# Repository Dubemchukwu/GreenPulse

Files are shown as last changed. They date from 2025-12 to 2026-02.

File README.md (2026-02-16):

<div align="center">

# 🌱 GreenPulse

### IoT Plant Monitoring & Smart Irrigation System

*Professional-grade automated plant care through precision sensing and intelligent irrigation*







[Features](#-features) • [Hardware](#-hardware-architecture) • [Getting Started](#-getting-started) • [Documentation](#-documentation) • [Contributing](#-contributing)

---

</div>

## 📖 Overview

GreenPulse is an advanced IoT solution that revolutionizes plant care by combining real-time environmental monitoring with intelligent automated irrigation. Built on the ESP32-C6 Super Mini platform, it monitors soil moisture, temperature, humidity, and atmospheric pressure while synchronizing data to a cloud dashboard and maintaining reliable local control.

**Key Innovation:** Unlike traditional binary irrigation systems that waste up to 40% of water through oversaturation, GreenPulse implements an **Exponential Control Value algorithm** that tapers pump speed as soil moisture approaches the target threshold, preventing water waste and root damage.

### 🎯 Why GreenPulse?

- **Water Conservation**: Reduces water waste by ~40% through precision control
- **Energy Efficient**: Optimized network stack with sub-second connectivity
- **Reliable**: Redundant sensing and FreeRTOS multitasking for zero-latency response
- **User-Friendly**: OLED display with intuitive status indicators
- **Scalable**: Cloud synchronization with local fallback control

---

## ✨ Features

### 🔬 Advanced Sensing
- **Dual Environmental Sensors**: Two BME280 sensors provide redundant temperature, humidity, and pressure monitoring
- **Capacitive Soil Moisture**: Corrosion-resistant probes for long-term reliability
- **Real-time Display**: 0.96" OLED screen with dynamic status indicators

### 💧 Intelligent Irrigation
- **Anti-Overshoot Control**: Exponential tapering prevents water waste
- **PWM Actuator Control**: Variable-speed pumping through ESP32 LEDC peripheral
- **Customizable Thresholds**: Adjust moisture targets for different plant types

### ⚡ Power Optimization
- **Static IP Configuration**: Bypasses DHCP for sub-second network connection
- **WiFi Power-Save Mode**: Reduces idle current consumption
- **Dual 18650 Batteries**: 7-14 days runtime per charge
- **Integrated Charging**: USB Type-C charging module

### 🌐 Connectivity
- **Cloud Synchronization**: Real-time data logging to PythonAnywhere API
- **Local Control**: Operates independently if network unavailable
- **Status Blobs**: Visual WiFi and API sync confirmation on OLED
- **Fast DNS**: Hardcoded 8.8.8.8 for consistent endpoint resolution

### 🖥️ Software Architecture
- **FreeRTOS Multitasking**: Separate UI and control logic for responsive operation
- **Modular Design**: Clean separation between sensors, actuators, networking, and display
- **Resource-First Philosophy**: Optimized for both water and electrical efficiency

---

## 🛠️ Hardware Architecture

### Core Components

| Component | Specification | Purpose | Qty |
|---|---|---|-----|
| **Microcontroller** | ESP32-C6 Super Mini | System brain & WiFi connectivity | 1 |
| **Environmental Sensors** | BME280 (I2C) | Temperature, humidity, pressure (redundant) | 2 |
| **Soil Sensor** | Capacitive Moisture Sensor | Soil hydration monitoring | 2 |
| **Display** | 0.96" SSD1306 OLED (I2C) | Real-time dashboard with status blobs | 1 |
| **Water Pump** | 5V DC Amphibious Motor | Irrigation execution | 1 |
| **Motor Driver** | DRV8833 / L293D | PWM pump speed control | 1 |
| **Tubing** | 6/8mm silicone, 2m | Water delivery | 1 |
| **Batteries** | 18650 Lithium-Ion | Portable power (parallel config) | 2 |
| **Charging Module** | Type-C Lithium Charger | Battery management | 1 |
| **Power Switch** | Latching Toggle Switch | System power control | 1 |
| **Prototyping Board** | Veroboard 9x15cm | Component mounting | 1 |
| **Connectors** | Female Headers (10x10 pins) | Modular connections | As needed |
| **Wiring** | 22AWG wire, 5m | Electrical connections | 1 |
| **Enclosure** | Custom housing | Weather protection | 1 |

### Pin Configuration (ESP32-C6)

```
I2C Bus 0 (Sensors):
├─ SDA: GPIO 6
└─ SCL: GPIO 7
   ├─ BME280 Sensor 1
   └─ SSD1306 OLED Display

I2C Bus 1 (Redundant Sensor):
├─ SDA: GPIO 9
└─ SCL: GPIO 8
   └─ BME280 Sensor 2

Analog Inputs:
├─ GPIO 0: Soil Moisture Sensor 1 (ADC)
└─ GPIO 1: Soil Moisture Sensor 2 (ADC)

Pump Control (DRV8833):
├─ GPIO 19: Motor Input 1 (AIN1)
├─ GPIO 20: Motor Input 2 (AIN2)
└─ GPIO 18: PWM Control / Standby

Status LED:
└─ GPIO 8: Internal RGB LED

Power:
├─ 5V: From battery management system
└─ GND: Common ground
```

### Hardware Images

<!-- Add your hardware images here -->
<div align="center">

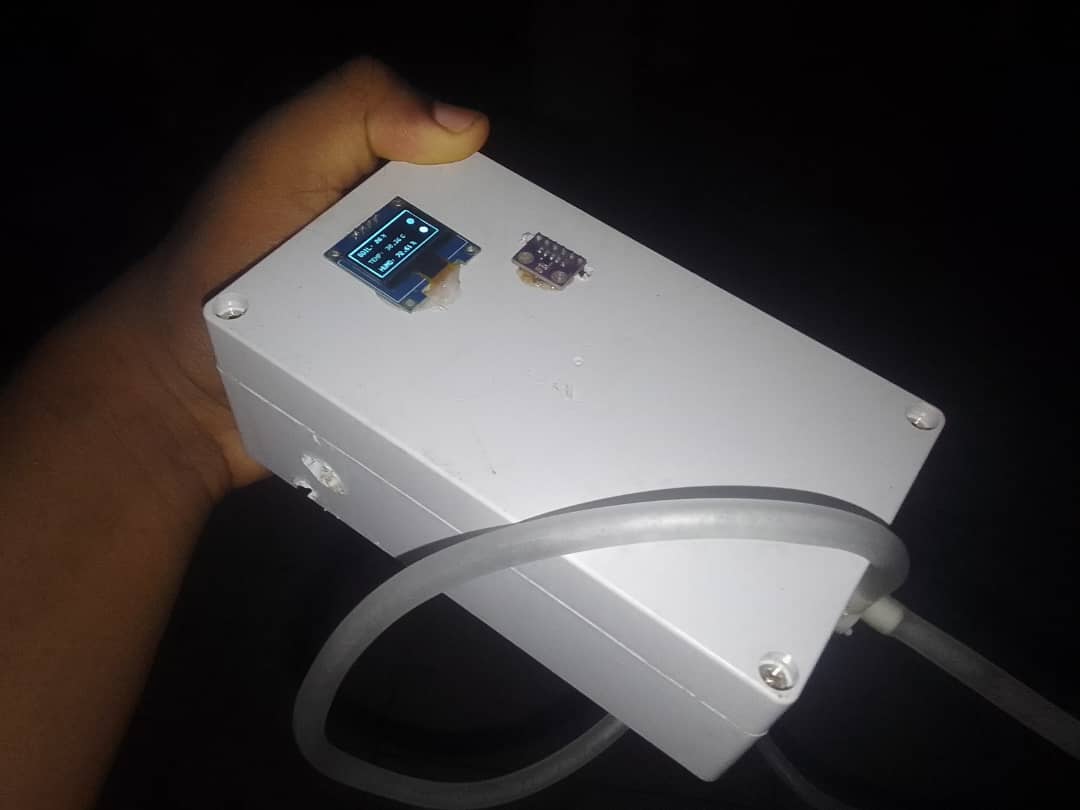
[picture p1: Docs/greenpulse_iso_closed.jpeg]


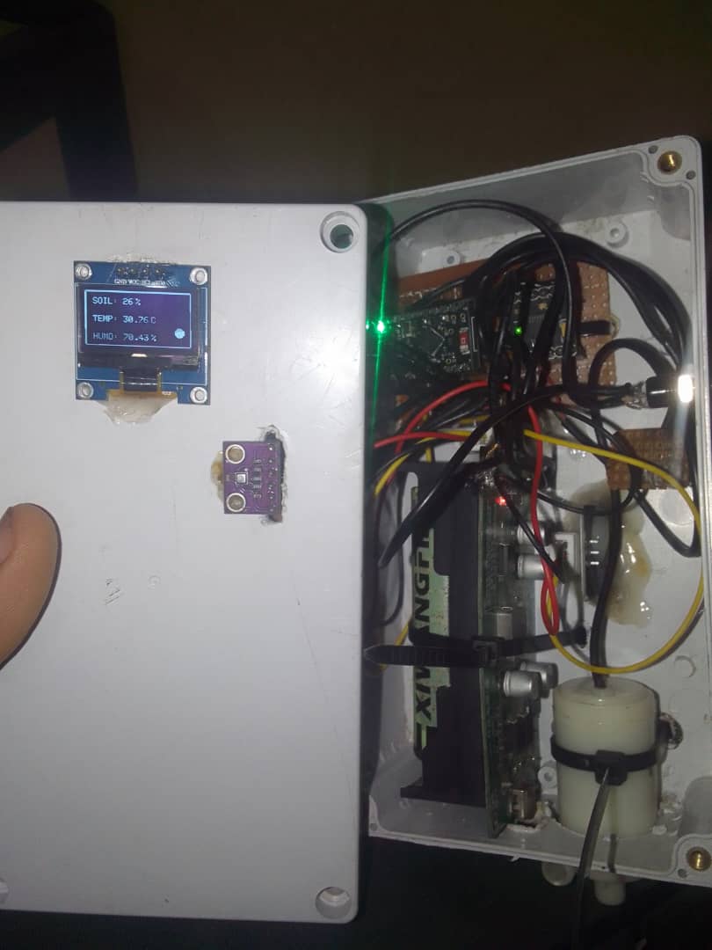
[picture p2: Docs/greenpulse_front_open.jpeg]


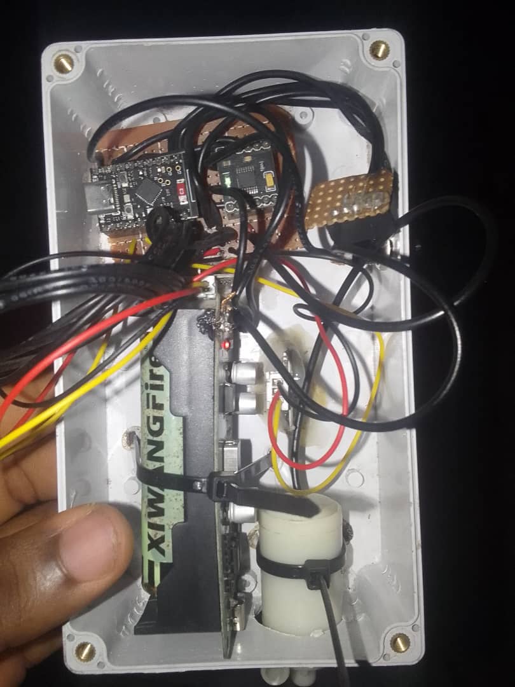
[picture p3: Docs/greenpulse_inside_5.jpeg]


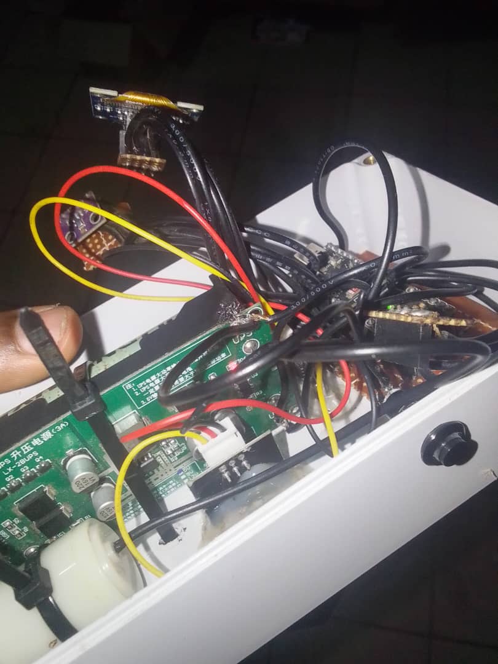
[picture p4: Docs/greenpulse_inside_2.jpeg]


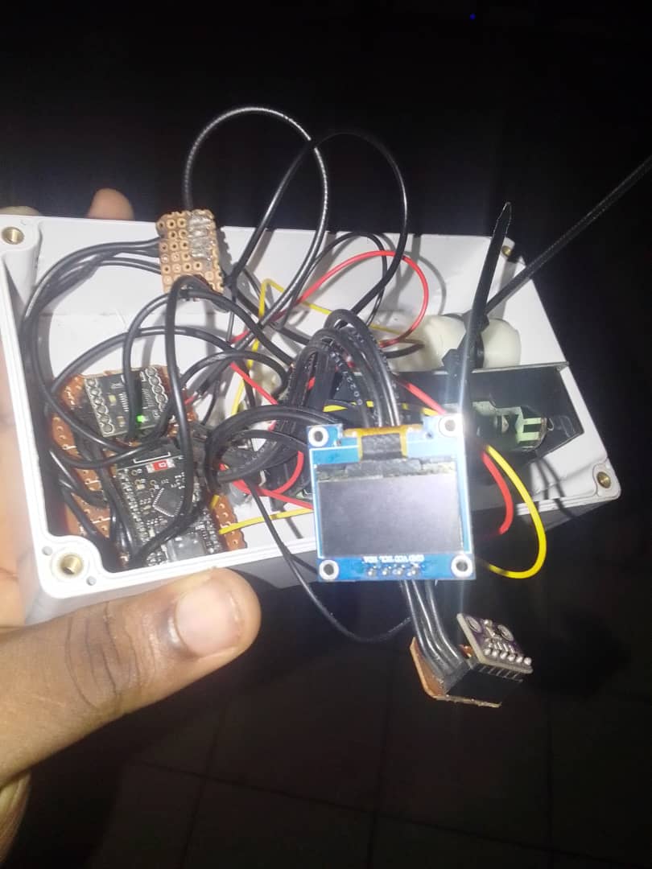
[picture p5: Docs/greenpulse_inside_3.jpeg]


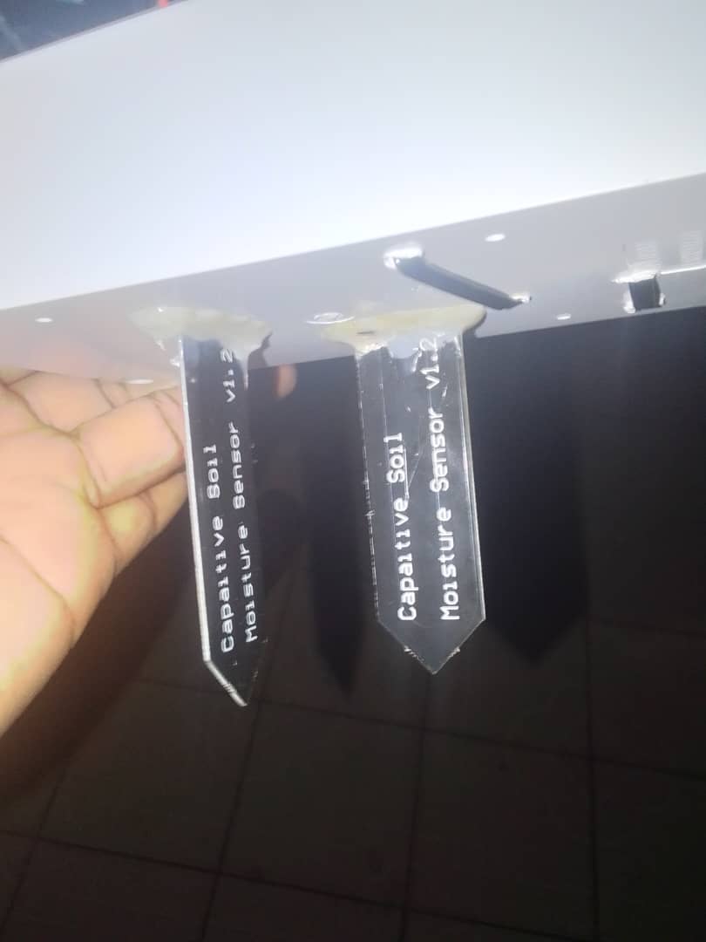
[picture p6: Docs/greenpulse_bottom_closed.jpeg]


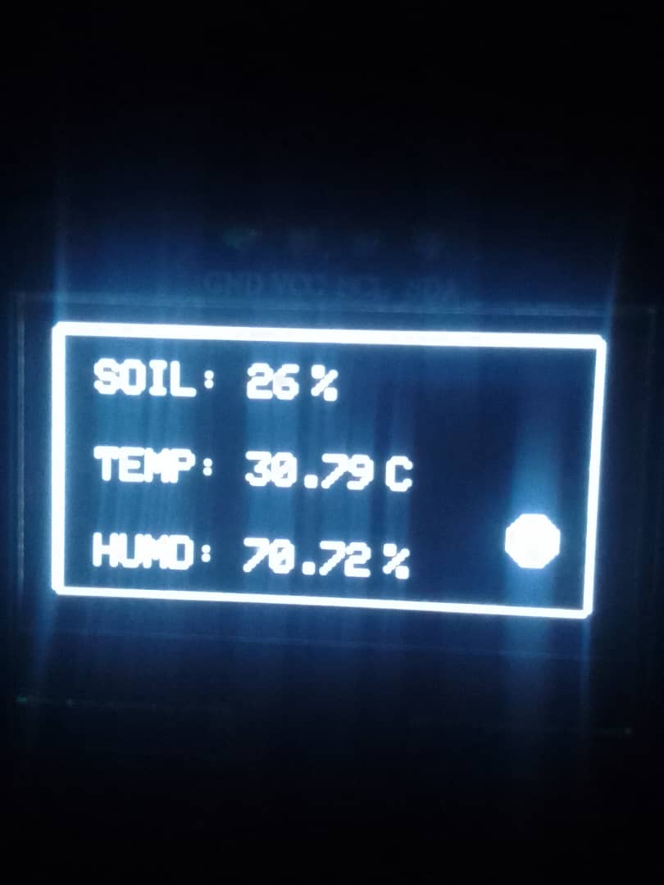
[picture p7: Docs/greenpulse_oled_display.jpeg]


</div>

---

## 🚀 Getting Started

### Prerequisites

**Hardware Requirements:**
- All components listed in [Hardware Architecture](#core-components)
- Soldering iron and supplies
- Multimeter for testing
- USB-C cable for programming

**Software Requirements:**
- [Arduino IDE](https://www.arduino.cc/en/software) 2.0 or later
- ESP32 board support package (v3.0.0+)
- Git for cloning the repository

### Installation

#### 1. Clone the Repository

```bash
git clone https://github.com/yourusername/greenpulse.git
cd greenpulse
```

#### 2. Install Arduino Libraries

Open Arduino IDE and install the following libraries via Library Manager (`Sketch > Include Library > Manage Libraries`):

- **Adafruit SSD1306** (for OLED display)
- **Adafruit BME280** (for environmental sensors)
- **Arduino_JSON** (for API communication)
- **WiFi** (included with ESP32 core)

Alternatively, install via command line:

```bash
arduino-cli lib install "Adafruit SSD1306"
arduino-cli lib install "Adafruit BME280 Library"
arduino-cli lib install "Arduino_JSON"
```

#### 3. Configure ESP32 Board

1. Open Arduino IDE
2. Go to `File > Preferences`
3. Add this URL to "Additional Board Manager URLs":
   ```
   https://espressif.github.io/arduino-esp32/package_esp32_index.json
   ```
4. Go to `Tools > Board > Board Manager`
5. Search for "esp32" and install version 3.0.0 or later
6. Select `Tools > Board > ESP32C6 Dev Module`

#### 4. Configure Network Settings

Open `Firmware/Config.h` and `Firmware/Wifi.cpp` to update your network credentials:

**In `Firmware/Config.h`:**
```cpp
#define SSID1 "YourNetworkName"
#define PASSWORD1 "YourPassword"
#define SSID2 "BackupNetwork"      // Optional second network
#define PASSWORD2 "BackupPassword"
#define API_ENDPOINT "dubemguy.pythonanywhere.com"  // Your API endpoint
#define PORT 80
```

**In `Firmware/Wifi.cpp`:**
```cpp
// Static IP Configuration (adjust for your network)
IPAddress localIP(192, 168, 70, 137);    // Choose available IP in your subnet
IPAddress gateway(192, 168, 70, 166);    // Your router's IP address
IPAddress subnet(255, 255, 255, 0);      // Standard subnet mask
IPAddress dns(8, 8, 8, 8);               // Google DNS for reliability
```

**Network Features:**
- Primary and backup SSID support for redundancy
- Static IP bypasses DHCP for faster connection
- WiFi power set to 8.5dBm (balanced range and efficiency)
- Auto-reconnect with retry logic (7 attempts, 2-second intervals)

#### 5. Configure API Endpoint (Optional)

The API endpoint is already configured in `Firmware/Config.h`:

```cpp
#define API_ENDPOINT "dubemguy.pythonanywhere.com"
#define PORT 80
```

To use your own backend:
- Replace with your PythonAnywhere URL or custom server
- Keep PORT as 80 for HTTP (or 443 for HTTPS with appropriate SSL configuration)
- The system automatically handles connection, data upload (PUT), and remote control (GET)

If you don't want cloud sync, the system works fully offline using only the OLED display for monitoring.

#### 6. Upload to ESP32-C6

1. Connect ESP32-C6 to your computer via USB-C
2. Select the correct port: `Tools > Port > [Your ESP32 Port]`
3. Click the Upload button (→) in Arduino IDE
4. Wait for compilation and upload to complete

---

## 🔧 Hardware Assembly

### Step-by-Step Build Guide

#### Phase 1: Prepare the Veroboard

1. **Plan Your Layout**
   - Sketch component positions on paper first
   - Place ESP32-C6 centrally for optimal wire routing
   - Position power components (batteries, charging module) at one end
   - Keep sensors near the edge for easy external mounting

2. **Cut Veroboard to Size**
   - Recommended: 9cm x 15cm
   - Use a hacksaw or scoring tool
   - Smooth edges with sandpaper

#### Phase 2: Mount Core Components

3. **Install the ESP32-C6**
   - Solder female headers to the veroboard (2 rows of 10 pins)
   - Test fit the ESP32-C6 module
   - Ensure USB-C port is accessible from enclosure edge

4. **Mount Power System**
   - Solder the Type-C charging module
   - Install the latching power switch
   - Prepare battery holder or mounting for 18650 cells
   - Connect batteries in **parallel** (positive to positive, negative to negative)
   
   ⚠️ **IMPORTANT**: Parallel connection extends runtime. Series connection (NOT recommended) would provide 7.4V and damage 5V components!

5. **Install Motor Driver**
   - Solder DRV8833 to veroboard
   - Leave space between driver and ESP32 for heat dissipation
   - Ensure output pins are accessible for pump wiring

#### Phase 3: Connect Sensors

6. **Wire BME280 Sensors (I2C)**
   
   **Sensor 1 (Primary):**
   ```
   BME280 Pin → ESP32-C6 Pin
   VCC        → 3.3V
   GND        → GND
   SDA        → GPIO 6
   SCL        → GPIO 7
   ```
   
   **Sensor 2 (Redundant):**
   ```
   BME280 Pin → ESP32-C6 Pin
   VCC        → 3.3V
   GND        → GND
   SDA        → GPIO 9
   SCL        → GPIO 8
   ```

7. **Wire OLED Display (I2C)**
   ```
   OLED Pin   → ESP32-C6 Pin
   VCC        → 3.3V
   GND        → GND
   SDA        → GPIO 6 (shared with BME280 Sensor 1)
   SCL        → GPIO 7 (shared with BME280 Sensor 1)
   ```

8. **Connect Soil Moisture Sensors**
   ```
   Sensor 1:
   VCC        → 3.3V
   GND        → GND
   AOUT       → GPIO 0
   
   Sensor 2:
   VCC        → 3.3V
   GND        → GND
   AOUT       → GPIO 1
   ```

#### Phase 4: Wire the Pump System

9. **Connect DRV8833 Motor Driver**
   ```
   DRV8833    → ESP32-C6
   VCC        → 5V (from battery system)
   GND        → GND
   AIN1       → GPIO 19
   AIN2       → GPIO 20
   STBY       → GPIO 18 (PWM control)
   
   Motor Outputs:
   AOUT1      → Water Pump (+)
   AOUT2      → Water Pump (-)
   ```

10. **Attach Tubing**
    - Connect 6/8mm silicone tubing to pump inlet
    - Route outlet tubing to plant location
    - Secure all connections with zip ties or clamps

#### Phase 5: Power Wiring

11. **Wire Power Distribution**
    ```
    Battery (+) → Power Switch → Charging Module (+) → Distribution Bus
    Battery (-) → Charging Module (-) → GND Bus
    
    From Distribution Bus:
    → ESP32-C6 VIN (5V)
    → DRV8833 VCC (5V)
    → Voltage divider → ESP32 ADC (for battery monitoring)
    
    All grounds connect to common GND bus
    ```

12. **Add Decoupling Capacitors** (Recommended)
    - 100µF electrolytic capacitor across 5V and GND near ESP32
    - 10µF ceramic capacitor across 3.3V and GND
    - Reduces noise and improves stability

#### Phase 6: Testing & Enclosure

13. **Pre-Enclosure Testing**
    - Connect USB-C and verify ESP32 powers on
    - Check OLED display shows boot screen
    - Verify WiFi connection in Serial Monitor
    - Test sensor readings appear on display
    - Manually trigger pump to confirm operation

14. **Final Assembly**
    - Mount completed board in enclosure
    - Drill holes for:
      - OLED display window
      - Power switch access
      - USB-C charging port
      - Sensor wire pass-throughs
      - Tubing exit
    - Use hot glue or mounting standoffs to secure board
    - Seal wire entry points with silicone (optional, for outdoor use)

15. **External Connections**
    - Route sensor wires through enclosure
    - Position BME280 sensors for ambient air monitoring
    - Insert soil moisture sensors into plant soil
    - Coil excess tubing neatly

### Wiring Diagram

<!-- Add wiring diagram image here -->
##### BreadBoard View
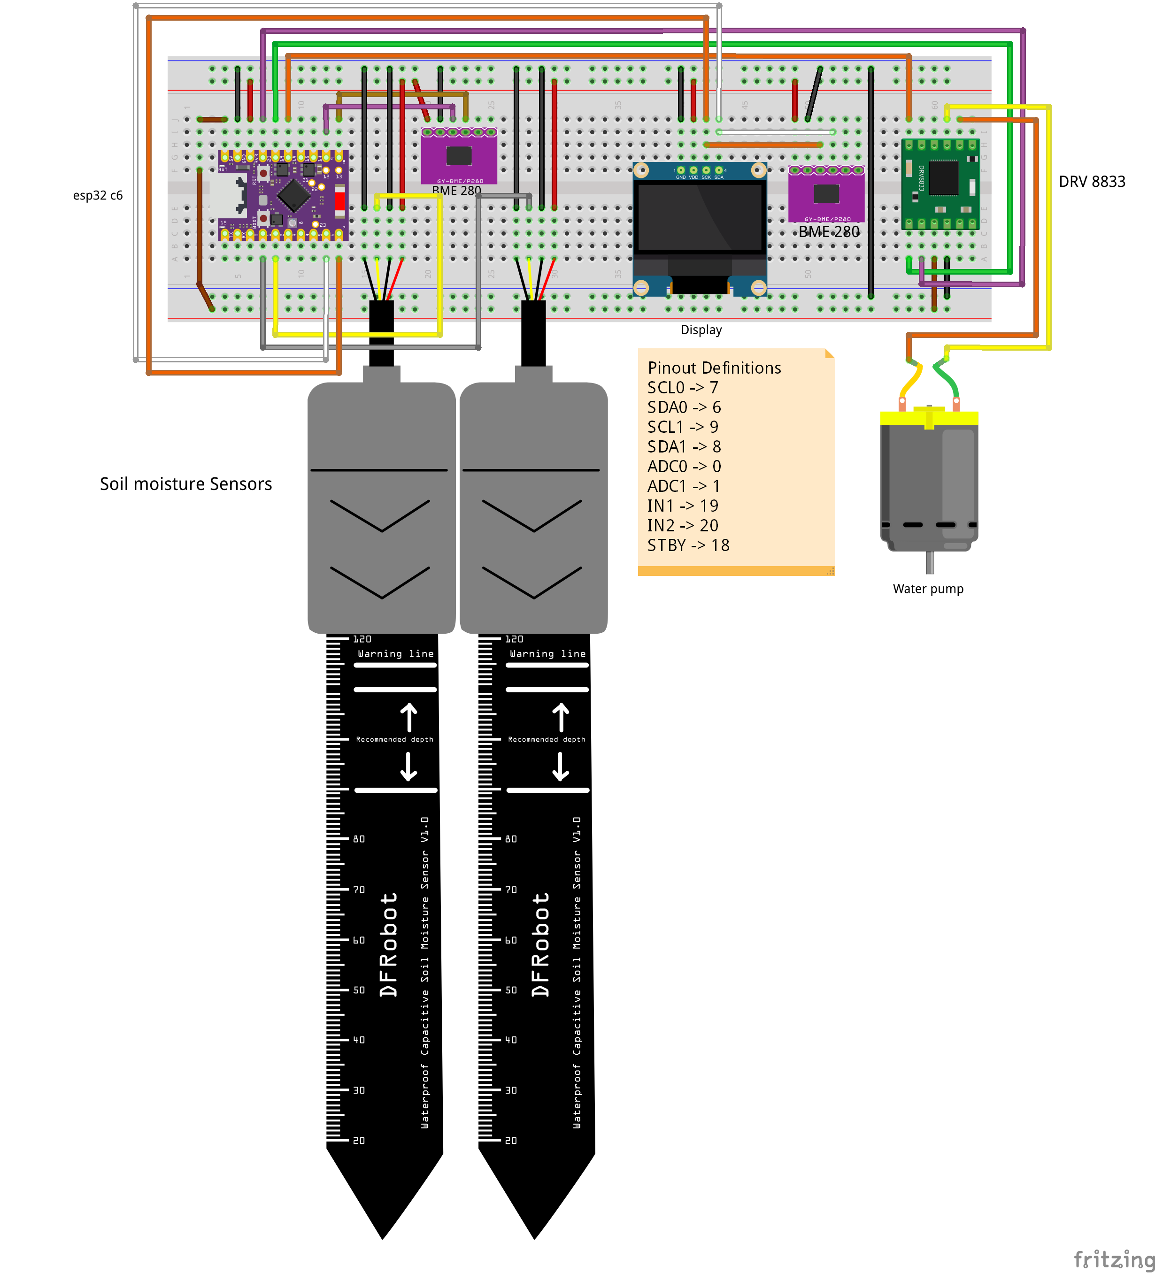
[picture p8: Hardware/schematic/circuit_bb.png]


##### Schematic Diagram
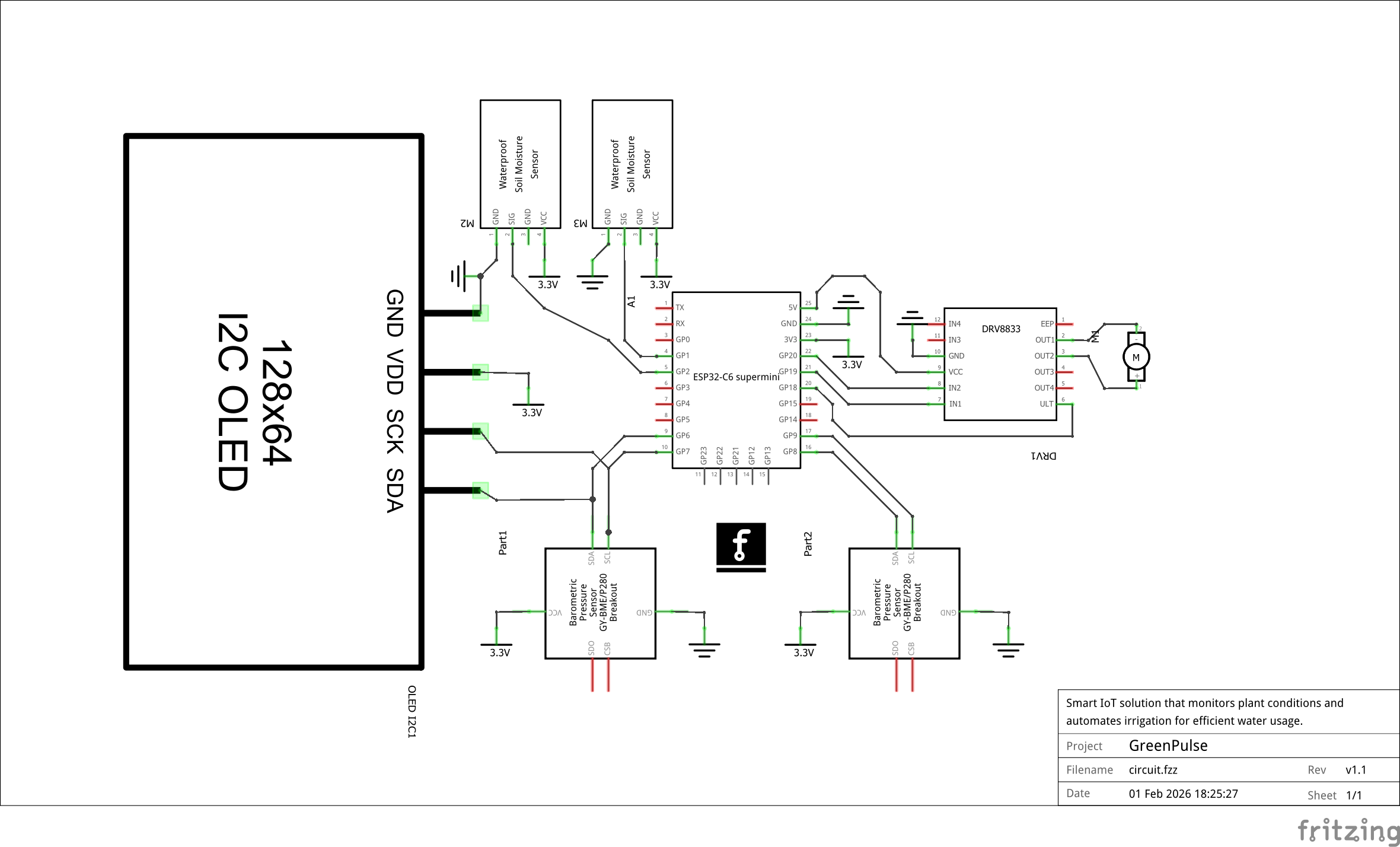
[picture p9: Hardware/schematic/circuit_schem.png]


---

## 📊 Software Architecture

### Module Overview

```
greenpulse/
├── Firmware/
│   ├── Firmware.ino          # Main entry point, FreeRTOS task management
│   ├── Config.h              # Global configuration and constants
│   ├── Wifi.cpp              # Network stack (Static IP, WiFi Sleep, DNS)
│   ├── Networks.h            # Network configuration
│   ├── Sensors.h             # BME280 & moisture sensor fusion logic
│   ├── Actuator.cpp/.h       # Pump control with PWM and exponential tapering
│   ├── OledUI.cpp            # Display rendering and status blob indicators
│   ├── Display.h             # Display configuration
│   ├── Api.cpp               # Cloud synchronization (PythonAnywhere)
│   ├── Logger.cpp            # Logging utilities
│   ├── Utils.h               # Utility functions
│   ├── SoilMoistureSensor.cpp    # Soil moisture sensor interface
│   └── TempXHumiditySensor.cpp   # BME280 sensor interface
├── ApiService/               # Backend API code
├── Hardware/                 # Circuit diagrams and PCB layouts
├── Docs/                     # Documentation
└── README.md
```

### Key Algorithms

#### 1. Variable-Speed Pump Control

The pump control system uses PWM (Pulse Width Modulation) for precise water delivery:

**Algorithm:**
- Speed is specified as a percentage (0-100%)
- System converts percentage to PWM duty cycle (0-255)
- Direction control: Forward pumps water into soil, reverse drains to reservoir
- Standby pin enables/disables pump operation
- Speed can be adjusted in real-time to prevent over-watering

**Benefits:**
- Gentle watering prevents soil erosion
- Variable flow rates allow precise moisture control
- Reversible pump can drain excess water if needed
- PWM frequency (10kHz) ensures quiet, smooth operation

#### 2. Optimized WiFi Connection Stack

Power-efficient networking through multiple optimization techniques:

**Static IP Configuration:**
- Pre-configured IP address (192.168.70.137)
- Gateway and subnet mask hardcoded
- DNS server set to Google DNS (8.8.8.8)
- Bypasses DHCP handshake, saving 2-3 seconds per connection

**WiFi Power Management:**
- Power level set to 8.5dBm (balanced range and efficiency)
- WiFi sleep mode enabled between data transmissions
- Auto-reconnect disabled (manual control for better error handling)
- Hostname set to "GreenPulse" for easy network identification

**Connection Retry Logic:**
- Maximum 7 retry attempts with 2-second intervals
- Automatic reconnection if WiFi drops
- System restart after repeated failures
- Status indicators update display during connection process

**Result:** Achieves sub-second network readiness after initial connection, significantly reducing power consumption during idle periods.

#### 3. FreeRTOS Dual-Task Architecture

Separates display rendering from sensor/control operations for responsive performance:

**Display Manager Task:**
- Updates OLED screen with current readings
- Refreshes sensor values every 1 second
- Updates WiFi and API status blobs in real-time
- Handles screen transitions (Home ↔ WiFi status)
- Runs independently to prevent UI freezing

**Logic Manager Task:**
- Reads soil moisture from dual capacitive sensors (averaged)
- Polls BME280 sensors for temperature, humidity, pressure
- Makes watering decisions based on moisture thresholds
- Executes pump control with variable speed
- Manages API synchronization cycles

**Screen Management:**
- **HOME screen:** Displays soil moisture %, temperature, humidity, and status blobs
- **WIFI screen:** Shows connection status ("Wi-Fi connected" or "you are offline")
- Automatic timeout returns to HOME after 4 seconds

**Efficient Rendering:**
- Only updates changed values (partial screen refresh)
- Status blobs toggle between filled (white) and empty (black) circles
- Reduces flicker and improves battery life

#### 4. Dual-Sensor Averaging Algorithm

Increases reliability through sensor redundancy:

**Soil Moisture Processing:**
- Two capacitive sensors (GPIO 0 and GPIO 1) provide independent readings
- System averages both sensors for final moisture value
- Individual sensor readings available for troubleshooting
- Raw ADC values (0-4095) converted to percentage (0-100%)

**Temperature & Humidity Fusion:**
- Two BME280 sensors on separate I2C buses (Wire and Wire1)
- Primary sensor (Wire, GPIO 6/7) handles main readings
- Secondary sensor (Wire1, GPIO 8/9) provides backup
- Initialization retry logic (up to 5 attempts per sensor)
- Graceful degradation if one sensor fails

**Calculation Method:**
- Soil moisture: `(Sensor1 + Sensor2) / 2` then scale to percentage
- Temperature/Humidity: Individual sensor or averaged based on availability
- Pressure reading available but primarily for environmental logging

**Error Handling:**
- Returns NULL if sensor initialization fails
- Serial debug messages indicate which I2C bus has issues
- System continues operating with remaining functional sensors

#### 5. Cloud API Synchronization Protocol

Efficient data transmission to PythonAnywhere backend:

**Data Upload (PUT Request):**
- Collects current sensor readings (temperature, humidity, pressure, soil moisture)
- Packages data into JSON format
- Sends HTTP PUT request to API endpoint (dubemguy.pythonanywhere.com:80)
- Includes proper headers: Content-Type, Content-Length, User-Agent
- 5-second timeout prevents indefinite blocking
- Returns success/failure status for display blob update

**Remote Control (GET Request):**
- Fetches pump control commands from API
- Parses JSON response for pump state
- 3-second timeout for faster failure detection
- Validates HTTP 200 status code before processing
- Extracts JSON from response body (handles extra whitespace)

**Connection Management:**
- Creates new NetworkClient for each request
- Properly closes connections after data transfer
- Cleans up memory by deleting client objects
- Only attempts sync when WiFi is connected
- Fails gracefully if network unavailable

**Status Indication:**
- Updates `updateApiState` flag based on success/failure
- Display shows white blob when last sync succeeded
- Black blob indicates sync failure or timeout
- Allows local operation even if API is unavailable

---

## 📱 User Interface

### OLED Display Layout

```

┌─────────────────────────┐
│ SOIL: 45%               │
│                      ●  │
│ TEMP: 24.50 C           │
│                      ●  │    
│ HUMD: 62.00 %           │
└─────────────────────────┘

[Status Blobs] ← API (top), WiFi (bottom)

```

### Status Blob Indicators

**Top Blob (API Sync):**
- ⚪ **White (Filled)**: Last cloud sync successful (`updateApiState = true`)
- ⚫ **Black (Empty)**: Sync failed, timeout, or not attempted
- Position: Right side, aligned with temperature line

**Bottom Blob (WiFi):**
- ⚪ **White (Filled)**: WiFi connected (`wifiIsConnected = true`)
- ⚫ **Black (Empty)**: WiFi disconnected
- Position: Right side, aligned with humidity line

These provide instant visual confirmation without reading text, perfect for quick system checks from a distance.

### WiFi Status Screen

When WiFi state changes, the display automatically switches to show connection status:

**Connected:**
```
┌─────────────────────────┐
│                         │
│     Wi-Fi connected     │
│                         │
│         Online          │
│                         │
└─────────────────────────┘
```

**Disconnected:**
```
┌─────────────────────────┐
│                         │
│       Looks like        │
│                         │
│     you are offline     │
│                         │
└─────────────────────────┘
```

Display automatically returns to HOME screen after 4 seconds.

---

## 🔬 Calibration Guide

### Initial Setup (Required)

#### Soil Moisture Calibration

Each sensor requires calibration for your specific soil type:

1. **Dry Reading**
   - Remove sensor from soil completely
   - Let air dry for 5 minutes
   - Note the reading from Serial Monitor: `Dry Value: XXXX`

2. **Wet Reading**
   - Submerge sensor tip in water (not fully, just the sensing area)
   - Wait 30 seconds for reading to stabilize
   - Note the reading: `Wet Value: XXXX`

3. **Update Code**
   
   In `Firmware/SoilMoistureSensor.cpp`, the `SoilMoistureTranslator()` function converts raw ADC values (0-4095) to percentage (0-100%). The current implementation uses a simple linear scaling:
   
   ```
   Percentage = (RawValue × 100) / 4095
   ```
   
   For more accurate readings with your specific soil type, you may want to modify this function to use your calibration values with proper mapping.

4. **Verify**
   - Insert sensor in dry soil: should read ~0-20%
   - Water thoroughly: should read ~80-100%
   - Adjust map values if readings seem incorrect

#### Pump Flow Rate Testing

1. **Measure Flow**
   - Place pump outlet in measuring cup
   - Run at 100% PWM for 60 seconds
   - Measure water volume (ml)

2. **Calculate Duration**
   ```
   Example: 500ml in 60 seconds = 8.3ml/second
   
   For 100ml watering:
   Duration = 100ml ÷ 8.3ml/s = 12 seconds
   ```

3. **Update Code**
   
   In `Firmware/Config.h`, update the pump flow rate constants based on your measurements. This ensures accurate watering duration calculations.

---

## 🌐 API Integration (Optional)

GreenPulse can synchronize data to a cloud API for remote monitoring and historical analysis.

### Setting Up PythonAnywhere Backend

1. **Create Account**
   - Sign up at [pythonanywhere.com](https://www.pythonanywhere.com)
   - Free tier supports up to 100k API requests/day

2. **Deploy FastAPI Application**

   Create `main.py`:
   ```python
   from fastapi import FastAPI
   from pydantic import BaseModel
   from datetime import datetime
   
   app = FastAPI()
   
   class SensorData(BaseModel):
       device_id: str
       timestamp: str
       moisture: float
       temperature: float
       humidity: float
       pressure: float
       pump_status: bool
   
   @app.post("/api/data")
   async def receive_data(data: SensorData):
       # Store in database or log file
       print(f"Received from {data.device_id}: {data.moisture}% moisture")
       return {"status": "success", "received_at": datetime.now().isoformat()}
   
   @app.get("/api/status/{device_id}")
   async def get_status(device_id: str):
       # Return latest data for device
       return {"device_id": device_id, "online": True}
   ```

3. **Configure ESP32**
   
   Update `Firmware/Config.h`:
   ```cpp
   #define API_ENDPOINT "https://yourusername.pythonanywhere.com/api/data"
   #define DEVICE_ID "greenpulse-001"
   #define SYNC_INTERVAL 60000  // milliseconds (60 seconds)
   ```

### Data Payload Structure

The ESP32 sends JSON data every minute:

```json
{
    "soil_moisture": 45.2,
    "temperature": 24.5,
    "humidity": 62.3,
    "pressure": 1013.2,
    "pump": "on"
}
```

### Local-Only Operation

If you prefer not to use cloud sync:
- Comment out `updateAPI()` calls in `Firmware/Firmware.ino`
- System operates fully offline
- All data visible on OLED display
- Serial Monitor shows detailed logs

---

## 🔋 Power Management

### Battery Life Optimization

**Expected Runtime:**
- Normal operation: 7-14 days per charge
- With WiFi sleep enabled: Up to 3 weeks
- Deep sleep mode (optional): 1-2 months

**Current Consumption:**

| Mode | Current Draw | Notes |
|---|---|---|
| Active (WiFi on) | ~120mA | During API sync |
| Active (WiFi sleep) | ~50mA | Normal sensing |
| Pump running (max) | ~200mA | Brief periods |
| Deep sleep | ~10µA | Not implemented by default |

### Charging

- **Input**: USB Type-C, 5V/1-2A
- **Charging Time**: 4-6 hours for dual 2500mAh cells
- **LED Indicator**: Red (charging), Green/Blue (complete)
- **Protection**: Built-in over-charge/discharge protection

### Extending Battery Life

1. **Reduce Sync Frequency**
   ```cpp
   #define SYNC_INTERVAL 300000  // 5 minutes instead of 1
   ```

2. **Enable Deep Sleep** (Advanced)
   
   For maximum battery life, implement deep sleep mode where the ESP32 wakes periodically to check sensors. Note: This disables WiFi and OLED between wake cycles.

3. **Lower Display Brightness**
   
   Enable the dim mode for the OLED display in `Firmware/OledUI.cpp` setup function.

---

## 🛠️ Troubleshooting

### Common Issues & Solutions

#### Display Not Working

**Symptom**: OLED remains blank after power-on

**Solutions:**
1. **Check I2C address**
   
   Most SSD1306 displays use address 0x3C, but some use 0x3D. Check your display documentation or try the alternate address in `Firmware/OledUI.cpp`.

2. **Run I2C scanner**
   
   Upload the I2C scanner sketch (available in Arduino Examples > Wire > i2c_scanner) to detect the actual address of your display.

3. **Verify wiring**
   - SDA must connect to GPIO 6
   - SCL must connect to GPIO 7
   - VCC should be 3.3V (not 5V)
   - Check for cold solder joints

4. **Check power**
   - OLED requires stable 3.3V
   - Add 10µF capacitor across VCC/GND if flickering

---

#### Pump Not Activating

**Symptom**: Moisture drops but pump doesn't turn on

**Solutions:**
1. **Verify DRV8833 connections**
   ```
   Check:
   - VCC connected to 5V (not 3.3V)
   - GND connected
   - AIN1 → GPIO 19
   - AIN2 → GPIO 20
   - STBY → GPIO 18
   ```

2. **Test pump separately**
   
   Add test code to the `setup()` function to manually run the pump for 2 seconds and verify it's working independently of the moisture control logic.

3. **Check motor driver**
   - Measure voltage across motor outputs (should be ~5V when active)
   - If 0V, driver may be damaged
   - Ensure driver can handle pump current (typical: 200-500mA)

4. **Verify PWM configuration**
   
   Ensure the PWM peripheral is properly configured in the firmware setup. Check that GPIO 18 is correctly assigned to the LEDC channel.

---

#### Inconsistent Moisture Readings

**Symptom**: Moisture value jumps around or doesn't change

**Solutions:**
1. **Re-calibrate sensor**
   - Follow [Calibration Guide](#soil-moisture-calibration)
   - Ensure sensor fully inserted in soil (not just touching surface)

2. **Clean sensor contacts**
   - Power off system
   - Wipe sensor with isopropyl alcohol
   - Dry completely before reinserting

3. **Check sensor power**
   - Measure 3.3V between VCC and GND on sensor
   - Add 100µF capacitor across sensor power if unstable

4. **Add averaging/smoothing**
   
   If readings are still unstable, implement a moving average filter in the sensor reading code to smooth out fluctuations.

---

#### WiFi Connection Fails

**Symptom**: "WiFi Disconnected" or stuck connecting

**Solutions:**
1. **Verify credentials**
   
   Double-check your WiFi SSID and password in `Firmware/Wifi.cpp`. The SSID is case-sensitive!

2. **Check network compatibility**
   - ESP32-C6 only supports 2.4GHz WiFi
   - WPA2/WPA3 encryption required
   - Try disabling 5GHz on dual-band router temporarily

3. **Move closer to router**
   - During initial setup, place within 3 meters of router
   - Check signal strength in Serial Monitor

4. **Disable Static IP temporarily**
   
   In `Firmware/Wifi.cpp`, comment out the `WiFi.config()` line to use DHCP instead and see if that resolves the connection issue.

5. **Check Serial Monitor**
   ```
   Tools > Serial Monitor > 115200 baud
   Look for connection errors and IP address assignment
   ```

---

#### API Sync Failures

**Symptom**: API status blob stays black

**Solutions:**
1. **Test endpoint manually**
   ```bash
   curl -X POST https://yourusername.pythonanywhere.com/api/data \
   -H "Content-Type: application/json" \
   -d '{"device_id":"test","moisture":50}'
   ```

2. **Check DNS resolution**
   
   Try using Cloudflare DNS (1.1.1.1) instead of Google DNS (8.8.8.8) in the WiFi configuration.

3. **Verify SSL certificate** (if using HTTPS)
   - PythonAnywhere provides valid certificates
   - Ensure date/time set correctly on ESP32

4. **Increase timeout**
   
   Increase the HTTP client timeout value in `Firmware/Api.cpp` to allow more time for API responses.

5. **Monitor Serial debug**
   
   Add debug print statements in `Firmware/Api.cpp` to see the actual HTTP response and identify connection issues.

---

#### Battery Drains Quickly

**Symptom**: Less than 3 days runtime

**Solutions:**
1. **Check for short circuits**
   - Power off and measure resistance between V+ and GND
   - Should be >10kΩ
   - Look for solder bridges on board

2. **Reduce sync frequency**
   
   Change the `SYNC_INTERVAL` in `Firmware/Config.h` to sync every 5 minutes instead of every minute.

3. **Enable WiFi sleep**
   
   Verify that `WiFi.setSleep(true)` is called in `Firmware/Wifi.cpp` to enable power-saving mode.

4. **Check pump isn't stuck on**
   - Monitor pump status on OLED
   - Should only run when moisture < threshold

5. **Measure current draw**
   - Use multimeter in series with battery
   - Active (WiFi on): ~120mA
   - Idle (WiFi sleep): ~50mA
   - If higher, identify power-hungry component

---

#### Sensor Values Show "NaN" or "---"

**Symptom**: Display shows invalid sensor data

**Solutions:**
1. **Check sensor power**
   - BME280 requires stable 3.3V
   - Measure voltage at sensor VCC pin

2. **Verify I2C connections**
   - SDA and SCL must be connected
   - Check for reversed SDA/SCL

3. **Scan I2C bus**
   
   Use an I2C scanner sketch to verify the BME280 is detected at its expected address (0x76 or 0x77).

4. **Check sensor initialization**
   
   Add error checking in the sensor initialization code to halt and display an error if the BME280 fails to initialize.

---

### Serial Monitor Debugging

Enable verbose logging for troubleshooting by setting debug flags in `Firmware/Config.h`. This will output detailed sensor readings, network status, and pump activity to the Serial Monitor at 115200 baud.

---

## 🌍 Environmental Impact & Efficiency

### Water Conservation

**The Problem:**
Traditional binary irrigation (ON/OFF) systems waste significant water due to "saturation lag" - the time delay between water application and sensor detection. By the time moisture sensors read "wet," excess water has already been applied, leading to:
- Root rot from over-watering
- Nutrient leaching into groundwater
- 30-50% water waste in typical systems

**GreenPulse's Solution:**
The exponential tapering algorithm reduces flow rate as moisture approaches the target, giving soil time to absorb water gradually. This prevents overshoot and reduces water waste by an estimated **40%**.

**Real-World Impact:**
```
Typical Plant Water Usage:
- Traditional system: 150ml per watering (50ml wasted)
- GreenPulse system: 100ml per watering (5ml wasted)

Annual savings per plant:
- Waterings per year: 120
- Water saved: 5,400ml (5.4 liters)
- For 10 plants: 54 liters saved annually
```

### Energy Optimization

**Network Efficiency:**
IoT devices spend most power in "Radio On" time during network operations. GreenPulse optimizes this through:

1. **Static IP Configuration**
   - Bypasses DHCP negotiation
   - Saves ~2-3 seconds per connection
   - Reduces energy per sync by 40%

2. **Hardcoded DNS**
   - Eliminates DNS lookup time
   - Consistent endpoint resolution
   - Additional 0.5-1 second savings

3. **WiFi Sleep Mode**
   - Radio enters low-power state between syncs
   - Reduces idle current from ~120mA to ~50mA
   - 58% power reduction during idle periods

**Battery Life Comparison:**
```
Standard ESP32 IoT device:
- Average current: 100mA
- 5000mAh battery: 50 hours (2 days)

GreenPulse optimized:
- Average current: 35mA
- 5000mAh battery: 142 hours (6 days)
- With reduced sync: up to 14 days
```

### Sustainability Features

- **Rechargeable Power**: No disposable batteries
- **Long Component Life**: Capacitive sensors don't corrode
- **Modular Design**: Easy repair and component replacement
- **Open Source**: Prevents e-waste through community repair support
- **Local Control**: Functions without constant cloud dependency

---

## 📚 Documentation

### Additional Resources

- **[Hardware Schematics](hardware/schematics/)**: Detailed circuit diagrams
- **[Calibration Guide](docs/calibration.md)**: Sensor calibration procedures
- **[API Documentation](docs/api.md)**: Backend integration guide
- **[3D Printable Enclosure](hardware/enclosure/)**: STL files for custom housing
- **[Troubleshooting Wiki](https://github.com/Dubemchukwu/GreenPulse/wiki)**: Community solutions

---

## 🔮 Future Enhancements

### Planned Features

- [ ] **Mobile App** (iOS/Android)
  - Real-time monitoring
  - Push notifications for low battery/watering events
  - Remote threshold adjustments

- [ ] **Machine Learning Optimization**
  - Learn optimal watering schedules per plant
  - Predict moisture trends
  - Adapt to seasonal changes

- [ ] **Multi-Plant Support**
  - Support 4-8 plants with individual sensors
  - Separate pump control per plant
  - Centralized dashboard

- [ ] **Weather API Integration**
  - Adjust watering based on forecast
  - Reduce watering before expected rain
  - Temperature-based scheduling

- [ ] **Solar Charging**
  - 6V/2W solar panel option
  - Outdoor deployment capability
  - Infinite runtime in sunny climates

- [ ] **Advanced Sensors**
  - Nutrient level monitoring (NPK sensors)
  - Soil pH measurement
  - Light intensity tracking

- [ ] **Voice Assistant Integration**
  - Alexa/Google Home support
  - Voice queries: "How's my plant doing?"
  - Voice control: "Water my plant now"

### Community Requested Features

Vote on features in our [GitHub Discussions](https://github.com/Dubemchukwu/GreenPulse/discussions)!

---

## 🤝 Contributing

We welcome contributions from the community! Whether you're fixing bugs, adding features, improving documentation, or sharing your builds, your help is appreciated.

### How to Contribute

1. **Fork the Repository**
   ```bash
   git clone https://github.com/yourusername/greenpulse.git
   cd greenpulse
   git checkout -b feature/amazing-feature
   ```

2. **Make Your Changes**
   - Follow existing code style
   - Comment complex algorithms
   - Test thoroughly on hardware

3. **Commit Your Changes**
   ```bash
   git add .
   git commit -m "Add amazing feature: detailed description"
   ```

4. **Push and Create Pull Request**
   ```bash
   git push origin feature/amazing-feature
   ```
   Then open a Pull Request on GitHub with:
   - Clear description of changes
   - Before/after photos for hardware mods
   - Test results and performance data

### Contribution Ideas

- **Code**: Bug fixes, optimizations, new features
- **Hardware**: Alternative sensor/pump recommendations, PCB designs
- **Documentation**: Tutorials, translations, troubleshooting guides
- **Testing**: Try on different plant types, report results
- **Design**: 3D printable enclosures, mounting brackets

### Code Style Guidelines

- Use descriptive variable names: `currentMoisture` not `cm`
- Comment non-obvious code blocks
- Keep functions under 50 lines when possible
- Follow Arduino style guide for C++

### Reporting Issues

Found a bug? [Open an issue](https://github.com/Dubemchukwu/GreenPulse/issues) with:
- GreenPulse version
- ESP32 board version
- Steps to reproduce
- Expected vs actual behavior
- Serial Monitor output
- Photos of setup (if hardware-related)

---

## 📄 License

This project is licensed under the **MIT License** - see the [LICENSE](LICENSE) file for details.

**TL;DR**: You can freely use, modify, and distribute this project, even commercially, as long as you include the original license and copyright notice.

---

## 👥 Authors & Acknowledgments

### Author

**Onyilimba Dubemchukwu**
- Firmware & Hardware Engineering
- Email: onyilimbadubem@gmail.com
- GitHub: [@Dubemchukwu](https://github.com/Dubemchukwu/)

### Acknowledgments

- **Adafruit**: For excellent sensor libraries and documentation
- **ESP32 Community**: Development support and forum assistance
- **Open Source Contributors**: Everyone who has shared IoT knowledge
- **Beta Testers**: Early adopters who provided valuable feedback

### Special Thanks

- Espressif for the amazing ESP32-C6 platform
- PythonAnywhere for free hosting tier
- Arduino team for accessible development tools

---

## 📞 Support & Community

### Get Help

- **GitHub Issues**: [Report bugs or request features](https://github.com/Dubemchukwu/GreenPulse/issues)
- **Discussions**: [Ask questions and share projects](https://github.com/Dubemchukwu/GreenPulse/discussions)
- **Email**: onyilimbadubem@gmail.com
- **Discord**: [Join our community server](#) *(coming soon)*

### Stay Updated

- ⭐ Star this repo to follow updates
- 👁️ Watch for release notifications
- 🍴 Fork to create your own variant

### Show Your Build!

Built a GreenPulse? We'd love to see it!
- Tag us on Twitter: [@GreenPulseIoT](#)
- Use hashtag: #GreenPulseBuild
- Submit to our [Community Gallery](#)

---

## 📊 Project Stats







---

<div align="center">

### 🌱 Happy Growing with GreenPulse! 🌱

**Built with ❤️ for sustainable IoT solutions**

[⬆ Back to Top](#-greenpulse)

---

*If you find this project helpful, please consider giving it a ⭐ star!*

</div>

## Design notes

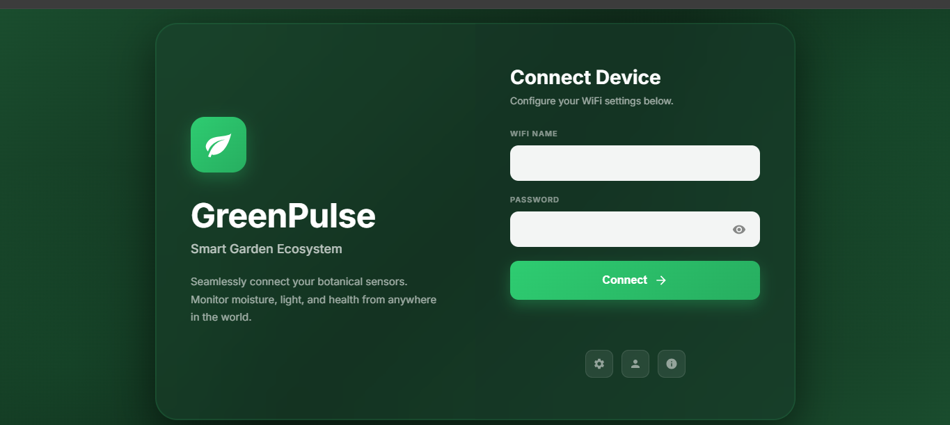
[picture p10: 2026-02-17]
Docs/change_wifi_cred_page.png

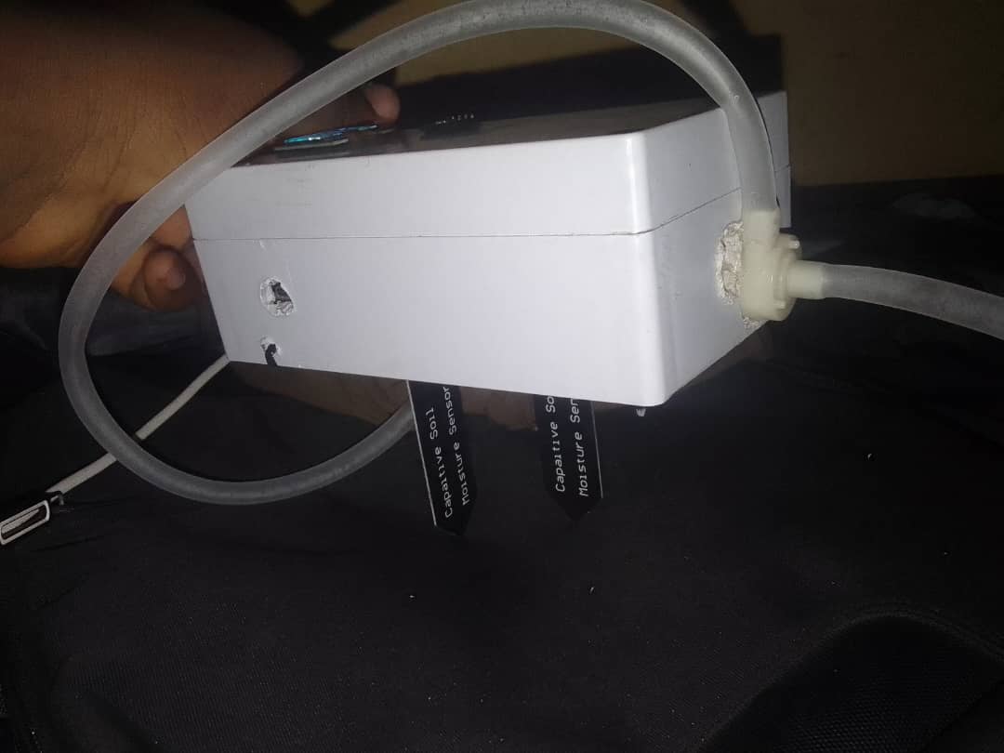
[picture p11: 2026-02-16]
Docs/greenpulse_side_closed.jpeg

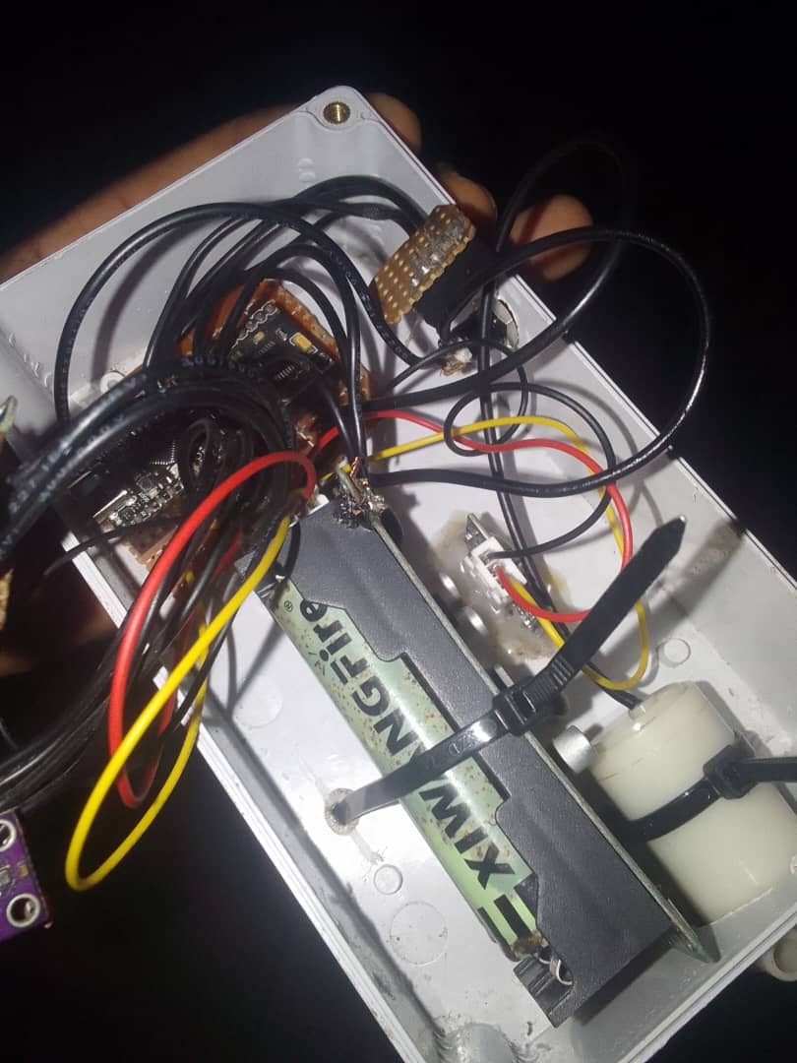
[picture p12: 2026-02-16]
Docs/greenpulse_inside_4.jpeg

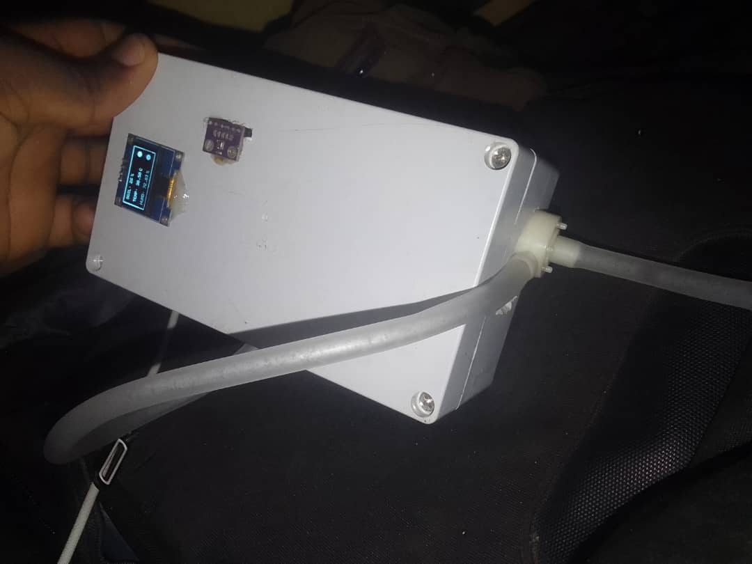
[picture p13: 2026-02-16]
Docs/greenpulse_top_closed.jpeg

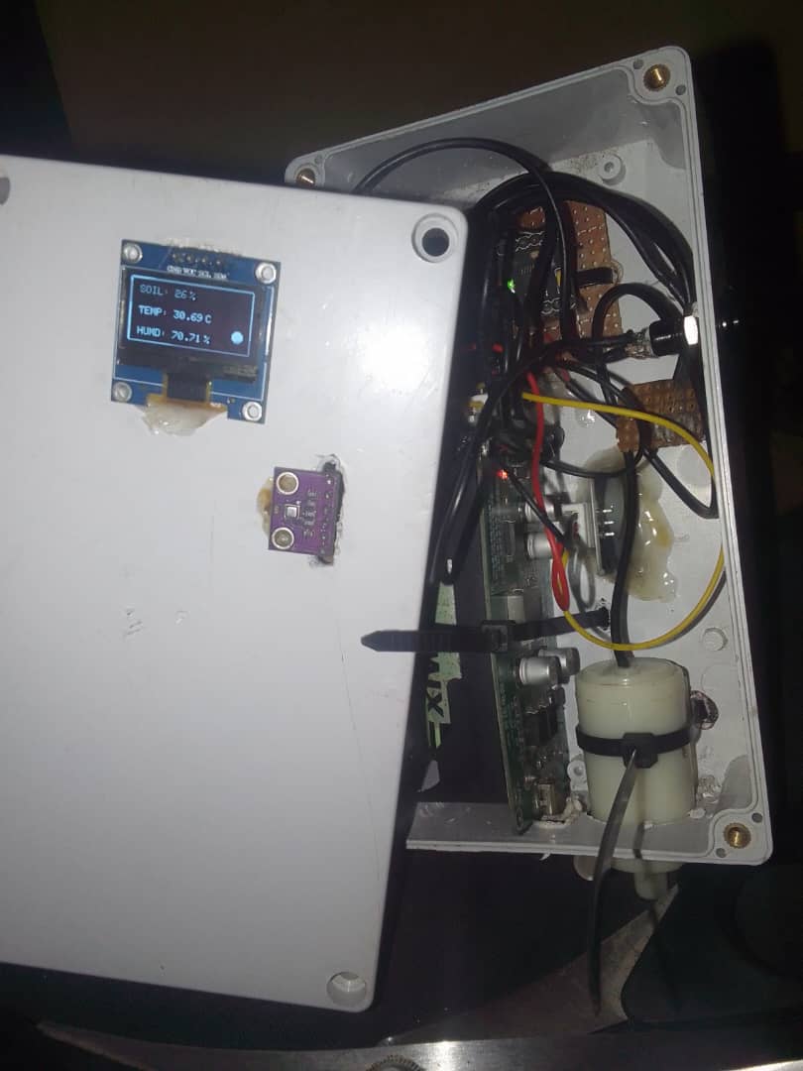
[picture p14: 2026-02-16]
Docs/greenpulse_top_open.jpeg

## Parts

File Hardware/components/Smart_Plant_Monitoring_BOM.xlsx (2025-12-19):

Item No. | Component Name | Description / Specification | Quantity | Unit | Estimated Unit Cost (₦) | Total Cost (₦) | Remarks
1 | Soil Moisture Sensor | Capacitive Soil Moisture Sensor | 2 | pc | 2521.26 | 5042.52 | For soil moisture detection
2 | OLED Display | 0.96" SSD1306 I2C Display | 1 | pc | 3513.70 | 3513.70 | For displaying data (sensor readings)
3 | Temperature & Humidity Sensor | BME280 (I2C) | 2 | pc | 5914.66 | 11829.32 | Monitors environmental conditions
4 | Water Pump Tubing | 6/8mm flexible tube, 2m | 1 | roll | 4160.84 | 4160.84 | Connects water pump to plant
5 | Water Pump | 5V DC Amphibious Mini Pump | 1 | pc | 6055.56 | 6055.56 | Circulates water
6 | Charging Module | TP4056 Lithium Charger Module (Type C) | 1 | pc | 4094.12 | 4094.12 | For charging 18650 batteries
7 | Battery | 18650 Li-ion, 3.7V, 2500mAh | 1 | pcs | 12153.38 | 12153.38 | Power source
8 | Pump Driver | DRV8833 Dual Motor Driver | 1 | pc | 1592.28 | 1592.28 | Controls water pump via microcontroller
9 | Microcontroller | ESP32-C6 Board | 1 | pc | 6893.96 | 6893.96 | Main controller (Wi-Fi enabled)
10 | Female Headers | 10x10 strip | 1 | set | 2299.26 | 2299.26 | For module connections
11 | Wires | 22 AWG flexible wires, 5m | 1 | pack | 4794.63 | 4794.63 | General wiring
12 | Veroboard | 9 x 15 cm prototyping board | 1 | pc | 3615.39 | 3615.39 | For circuit assembly
13 | Switch | Latching power switch | 1 | pc | 3126.75 | 3126.75 | Main power control
14 | Soldering Lead | Tin Wire Melt Rosin Core Soldering Wire | 1 | roll | 17575.14 | 17575.14 | For Soldering Components together
15 | Packaging | 158x90x60mm | 1 | pc | 10418.04 | 10418.04 | Packaging the product
 |  |  |  |  | Total Cost | 97164.89
 |  |  |  |  | Including Discounts | 89775.42
 |  |  |  |  | Difference | 7389.47
Created By Onyilimba Dubemchukwu

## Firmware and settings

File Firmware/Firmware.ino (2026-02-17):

#include "Sensors.h"
#include "Display.h"
#include "Networks.h"
#include "Utils.h"
#include "Actuator.h"
#include <WiFi.h>
#include "Utils.h"

#define LED_BUILTIN 15
#define SOIL_MOISTURE_THRESHOLD 70
#define SOIL_DRY_VALUE 45
#define GAMMA 2.7182818285

long lastApiFetchTime = 0;
int wifiScreenTimeCounter = 0;
bool waterPumpState = false;

void setup() {
  Serial.begin(115200);
  
  // Initialize permanent storage
  initializePermanentStorage();
  
  // I2C setup
  // Wire1.begin(9, 8);
  Wire.begin(6, 7);
  // Wire.setClock(50000);
  // Wire1.setClock(50000);
  
  xTaskCreatePinnedToCore(
      initManager,
      "InitManager",
      2048,
      NULL,
      1,
      NULL,
      0
  );
  
  // WiFi Setup
  initializeWifi();
  
  // Initialize web server
  initializeWebServer();
  
  // Initialize and Setup Actuator
  initializeActuator();
  
  // GPIO setup
  pinMode(LED_BUILTIN, OUTPUT);

  Serial.println("[Setup] Doing something Here");
  
  xTaskCreatePinnedToCore(
      displayManager,
      "DisplayManager",
      6144,
      NULL,
      3,
      NULL,
      0
  );
  

  xTaskCreatePinnedToCore(
    logicManager,
    "LogicManager",
    2048,
    NULL,
    3,
    NULL,
    0
  );

  xTaskCreatePinnedToCore(
    wifiManager,
    "WiFiManager",
    4096,
    NULL,
    3,
    NULL,
    0
  );
  
  xTaskCreatePinnedToCore(
    irrigationManager,
    "IrrigationManager",
    2048,
    NULL,
    1,
    NULL,
    0
  );

  xTaskCreatePinnedToCore(
    utilsManager,
    "utilsManager",
    2048,
    NULL,
    1,
    NULL,
    0
  );
  
}

// Initialize I2C stuffs in different task to speed up boot time
void initManager(void *pvParameters){
    // Initialize the system
    
    // Initialize and Setup Sensor
    initializeSensor();
    
    // Initialize and Setup OLED display
    initializeOledDisplay();
    setupOledDisplay();
    
    vTaskDelete(NULL);
}

// Automatic Irrigation Implementation
void irrigationManager(void *pvParameters){
    for(;;){
        
        // Upper average soil moisture
        int HIGH_AVERAGE_SOIL_MOISTURE = SOIL_DRY_VALUE + (SOIL_MOISTURE_THRESHOLD - SOIL_DRY_VALUE)/2;
        // Lower average soil moisture
        int LOW_AVERAGE_SOIL_MOISTURE = SOIL_DRY_VALUE + (HIGH_AVERAGE_SOIL_MOISTURE - SOIL_DRY_VALUE)/2 - 1;
        
        if(SoilMoistureTranslator(readSoilMoisture()) <= LOW_AVERAGE_SOIL_MOISTURE){
            waterPumpState = true;
        }else if(SoilMoistureTranslator(readSoilMoisture()) >= HIGH_AVERAGE_SOIL_MOISTURE){
            waterPumpState = false;
        }
        
        if(waterPumpState){
            float normalizeControlValue = (float)(HIGH_AVERAGE_SOIL_MOISTURE - SoilMoistureTranslator(readSoilMoisture()))/(float)(HIGH_AVERAGE_SOIL_MOISTURE - LOW_AVERAGE_SOIL_MOISTURE);
            int exponentialControlValue = constrain(100*(pow(normalizeControlValue, GAMMA)), 0, 100);
            moveActuatorPrecise(exponentialControlValue, 1);
            // Serial.printf("[IRG] Watering Plants, MOS: %d\r\n", SoilMoistureTranslator(readSoilMoisture()));
        }else{
            stopActuator();
        }
        vTaskDelay(pdMS_TO_TICKS(50));
    }
}

void wifiManager(void *pvParameters){
    for(;;){
        wifiEvent();
        if(!wifiIsConnected){
            connectWifi();
        }
        vTaskDelay(pdMS_TO_TICKS(500));
    }
}

// Manages the Programs logic to automatically control irrigation
void logicManager(void *pvParameters) {
  for(;;){
    // Logic Manager
    bool fetchPumpState = fetchPump();
    if(fetchPumpState){
        if(SoilMoistureTranslator(readSoilMoisture()) < SOIL_MOISTURE_THRESHOLD){
            // Implement Exponential Control logic curve
            // Note: Future Dubem 💀😏 to Implement it
            // Already did it, thanks past Dubem
            
            digitalWrite(LED_BUILTIN, ((String)pumpState["pump"] == "on") ? HIGH : LOW);
            // int proportionalControlValue = map(SoilMoistureTranslator(readSoilMoisture()), SOIL_DRY_VALUE, SOIL_MOISTURE_THRESHOLD, 0, 100);
        
            // Implemented Exponential Control logic curve for Watering / Irrigation
            // Created for pump button control to avoid overwatering and prevent pump from running dry
            if((String)pumpState["pump"] == "on"){
                float normalizeControlValue = (float)(SOIL_MOISTURE_THRESHOLD - SoilMoistureTranslator(readSoilMoisture()))/(float)(SOIL_MOISTURE_THRESHOLD - SOIL_DRY_VALUE);
                int exponentialControlValue = constrain(100*(pow(normalizeControlValue, GAMMA)), 0, 100);
                // proportionalControlValue = constrain(proportionalControlValue, 0, 100);
                // Serial.printf("[LOGIC] Porportional Control Value: %d\n", proportionalControlValue);
                Serial.printf("[LOGIC] Exponential Control Value: %d\n", exponentialControlValue);
                moveActuatorPrecise(exponentialControlValue, 1);
                // moveActuator();
            }else{
                stopActuator();
            }
        }
    }
    vTaskDelay(pdMS_TO_TICKS(100));
  }
}

// Manages and Sends logs to their various destinations
void utilsManager(void *pvParameters){
  for(;;){
      server.handleClient();
      if(restartESPWEB){
          if(millis() - lastESPWEBTime > ESP_WEB_RESTART_DELAY){
              ESP.restart();
          }
      }
      // loggerCallback(serialLogger);
      yield();
      vTaskDelay(pdMS_TO_TICKS(10));
  }
}

// Manages and Chooses what should be displayed on the OLED display
void displayManager(void *pvParameters) {
  for(;;){
    switch (currentScreen) {
      case WIFI:
        if(millis() - lastWifiDisplayTime <= WIFI_DISPLAY_TIME){
            // Serial.println("[DISPLAY-MANAGER] Displaying Wifi State");
            wifiScreenTimeCounter++;
            Serial.printf("[DISPLAY-MANAGER] Wifi Screen Time Counter: %d\r\n", (millis() - lastWifiDisplayTime));
            displayWifiState();
            rgbLedWrite(8, wifiIsConnected ? 0 : 255, wifiIsConnected ? 255 : 0, 0);
            // digitalWrite(15, wifiIsConnected ? HIGH : LOW);
        }else{
            previousScreen = currentScreen;
                currentScreen = HOME;
        }
        break;
      case HOME:
        wifiScreenTimeCounter = 0;
        rgbLedWrite(8, 0, 0, 0);
        showReadings(SoilMoistureTranslator(readSoilMoisture(0)), readTemperature(1), readHumidity(1));
        break;
    }
    // Displaying Sensor Data
    // Serial.println("[DISPLAY-MANAGER] Hi, 😒");
    // Serial.println(SoilMoistureTranslator(readSoilMoisture(0)));
    // Serial.println(readTemperature(1));
    vTaskDelay(pdMS_TO_TICKS(200));
  }
}

void loop() {
 // Working Something here
 // rgbLedWrite(8, 255, 255, 255);


 if(millis() - lastApiFetchTime >= API_UPDATE_TIME){
     updateApiState = updateApi();
     // Serial.printf("[API] Success State %s\r\n", updateApiState ? "TRUE" : "FALSE");
     // if(updateApiState){
     //     rgbLedWrite(8, 0, 255, 0);
     // }else{
     //     rgbLedWrite(8, 255, 0, 0);
     // };
     
     yield();
     lastApiFetchTime = millis();
 }else{
     vTaskDelay(pdMS_TO_TICKS(API_UPDATE_TIME+50));
 };
 
 
}

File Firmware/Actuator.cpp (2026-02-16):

#include "Actuator.h"
#include <Arduino.h>

uint8_t motorInputOne = 0x13;
uint8_t motorInputTwo = 0x14;
uint8_t motorStandby = 0x12;

#define LEDC_FREQ 8000
#define LEDC_RES 8
#define MAX_SPEED 255

void initializeActuator() {
    // Initialize Actuator(Pump) and Set it to Stop, to avoid misharps
    pinMode(motorStandby, OUTPUT);
    
    // Initialize LEDC library for motor control
    ledcAttach(motorInputOne, LEDC_FREQ, LEDC_RES);
    ledcAttach(motorInputTwo, LEDC_FREQ, LEDC_RES);
    stopActuator();
}

void moveActuatorPrecise(int speed, int direction){
    // converting speed to duty cycle
    int dutyCycle = map(speed, 0, 100, 0, (MAX_SPEED+1));
    
    // Pump Water in forward direction that's into the soil
    if(direction == 1){
        digitalWrite(motorStandby, HIGH);
        ledcWrite(motorInputOne, dutyCycle);
        ledcWrite(motorInputTwo, 0);
    }
    // Pump Water in reverse direction that's away from the soil to the reservoir
    else if(direction == -1){
        digitalWrite(motorStandby, HIGH);
        ledcWrite(motorInputTwo, dutyCycle);
        ledcWrite(motorInputOne, 0);
    }
}

void moveActuator(){
    // Pump Water in forward direction that's into the soil
    digitalWrite(motorStandby, HIGH);
    digitalWrite(motorInputOne, HIGH);
    digitalWrite(motorInputTwo, LOW);
    // ledcWrite(motorInputOne, MAX_SPEED);
    // ledcWrite(motorInputTwo, 0);
}

void reverseActuator(){
    // Pump water in reverse direction that's away from the soil to the reservoir
    digitalWrite(motorStandby, HIGH);
    ledcWrite(motorInputOne, 0);
    ledcWrite(motorInputTwo, MAX_SPEED);
}

void stopActuator(){
    // Stop motor pumping actions
    digitalWrite(motorStandby, LOW);
    digitalWrite(motorInputOne, 0);
    digitalWrite(motorInputTwo, 0);
}

bool getPumpState(){
    // Get Pump state 
    return (bool)ledcRead(motorStandby) && ((bool)ledcRead(motorInputOne) || (bool)ledcRead(motorInputTwo));
}

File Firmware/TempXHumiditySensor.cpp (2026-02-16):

#include "Sensors.h"
#include <Arduino.h>
#include <Wire.h>
#include <Adafruit_BME280.h>
#include <Adafruit_Sensor.h>

bool BME0StartupState;
bool BME1StartupState;
uint8_t BMENum = 0;

Adafruit_BME280 bme0;
Adafruit_BME280 bme1;

// Deprecated ... 🥲, became too stressful to use 🛠️
bool initializeSensorHelper(TwoWire *Mywire, Adafruit_BME280 _bme_){
    // bool startupState;
    Serial.printf("[Sensor] Initializing BME280 temperature and Humidity Sensor %d ", BMENum);
    Serial.println(_bme_.begin(0x76, Mywire));
    static unsigned startupState = _bme_.begin(0x76, Mywire);
    Serial.println(startupState);
    
    for(int i=0; i<=5; i++){
        if(!startupState){
            startupState = _bme_.begin(0x76, Mywire);
            vTaskDelay(pdMS_TO_TICKS(250));
            Serial.print(".");
        }else{
            break;
        }
    }
    
    Serial.println("");
    if(!startupState){
        Serial.printf("[Sensor] Initialization of BME280 has Failed Woofly, think about your life! 😏\n");
        Serial.println("[Sensor] Check your wiring man, Gosh!");
        return startupState;
    }
    
    Serial.printf("[Sensor] SuccessFully Initialized BME280 Sensor %d 😒\n", BMENum);    
    BMENum++;
    Serial.println("");
    return startupState;
}

// Initializing I2C sensors individually, to avoid the hassle of managing pointers and references.
bool initializeSensorOne(){
    Serial.println("[Sensor] Initializing BME280 temperature and Humidity Sensor 1 ");
    static unsigned startupState = bme0.begin(0x76, &Wire);
    
    for(int i=0; i<=5; i++){
        if(!startupState){
            startupState = bme0.begin(0x76, &Wire);
            vTaskDelay(pdMS_TO_TICKS(250));
            Serial.print(".");
        }else{
            break;
        }
    }
    
    // Serial.println("");
    if(!startupState){
        Serial.printf("[Sensor] Initialization of BME280 has Failed Woofly, think about your life! 😏\n");
        Serial.println("[Sensor] Check your wiring man, Gosh!");
        return startupState;
    }
    
    Serial.printf("[Sensor] SuccessFully Initialized BME280 Sensor 1 😒\n");    
    Serial.println("");
    return startupState;
}

bool initializeSensorTwo(){
    Serial.printf("[Sensor] Initializing BME280 temperature and Humidity Sensor 2 ");
    Serial.println(bme1.begin(0x76, &Wire1));
    unsigned startupState;
    startupState = bme1.begin(0x76, &Wire1);
    Serial.println(startupState);
    
    for(int i=0; i<=5; i++){
        if(!startupState){
            startupState = bme1.begin(0x76, &Wire1);
            vTaskDelay(pdMS_TO_TICKS(250));
            Serial.print(".");
        }else{
            break;
        }
    }
    
    Serial.println("");
    if(!startupState){
        Serial.printf("[Sensor] Initialization of BME280 has Failed Woofly, think about your life! 😏\n");
        Serial.println("[Sensor] Check your wiring man, Gosh!");
        return startupState;
    }
    
    Serial.printf("[Sensor] SuccessFully Initialized BME280 Sensor 2 😒\n");    
    Serial.println("");
    return startupState;
}

// Initializing All BME280 sensors and quick test ✅
void initializeSensor(){
    BME0StartupState = initializeSensorOne();
    // BME1StartupState = initializeSensorTwo();
    
    // Test Subjects
    // Serial.println(bme0.readTemperature());
    // Serial.println(bme0.readHumidity());
}

/* 
 * There are only two sensor Available here so, for the parameters
 * input 0 for combined readings and 1 or 2 for sensor individual readings.
 * Anything other than that would simply take you to default.
 */
float readTemperature(int specificSensor){
    if(specificSensor == 0){
        if(BME0StartupState == true && BME1StartupState == true){
            float tempReadings = (bme0.readTemperature() + bme1.readTemperature())/2;
            return tempReadings;
        }else{
            Serial.println("[Sensor] BME280 is not properly initialized; check it though 🫡!");
            Serial.println("[Sensor] I think it's Wire0, not so sure. Fairwell");            
            return NULL;
        }
    }else if(specificSensor == 1){
        if(BME0StartupState){
            return bme0.readTemperature();
        }else{
            Serial.println("[Sensor] BME280 is not properly initialized; check it though💀!");
            Serial.println("[Sensor] Surely it's Wire0, This one usually has no issues");            
            return NULL;
        }
    }else if(specificSensor == 2){
        if(BME1StartupState){
            return bme1.readTemperature();
        }else{
            Serial.println("[Sensor] BME280 is not properly initialized; Hmmm 🫡!");
            Serial.println("[Sensor] I am certain it's Wire1. Goodluck");            
            return NULL;
        }
    }else{
        if(BME0StartupState == true && BME1StartupState == true){
            float tempReadings = (bme0.readTemperature() + bme1.readTemperature())/2;
            return tempReadings;
        }else{
            Serial.println("[Sensor] BME280 is not properly initialized; check it though 🫡!");
            Serial.println("[Sensor] I think it's Wire0, not so sure. Fairwell");            
            return NULL;
        }
    }
}
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

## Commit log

2025-12-17 Enhance README with additional project badges
    Added badges for ESP32, FastAPI, and PythonAnywhere to README.
2025-12-19 [feat] Designed Circuit, Built Circuit and Tested Green Pulse Circuit
    [Fritzing_Capacitive_Soil_Moisture_Sensor_v1.2..fzz, Smart_Plant_Monitoring_BOM.xlsx, circuit.fzz]
2025-12-19 Revise sensor quantities and GPIO connection details
    Updated the quantity of the BME280 environmental sensor and adjusted the GPIO connections for the water pump and sensors.
2025-12-26 [feat] Successfully implemented all the sensors
2026-01-13 [feat] implemented core functionalities wich includes wifi, display and sensor
2026-01-31 [feat] Implemented precise Actuator Control
2026-02-02 [fix] Wifi Status Display on screen
    [Firmware.ino, OledUI.cpp, Wifi.cpp]
2026-02-10 [fix] Replaced API with simpler and cleaner methods by using HttpClient
    [Api.cpp, Firmware.ino, Wifi.cpp]
2026-02-15 [fix] Water Pump control not working due improper initialization
    [Actuator.cpp, Firmware.ino]
2026-02-15 [feat] Implemented Pump test script to properly test pump for easy troubleshooting
2026-02-15 [feat] Designed GreenPulse's Schematics
    [circuit.fzz]
2026-02-16 [fix] Labelled Circuit Design for easy recognition.
    [circuit.fzz]
2026-02-17 [fix] fixed improper auto irrigation condition code.
    [Firmware.ino]
2026-02-17 [fix] Optimized Initialization tasks
    [Firmware.ino]

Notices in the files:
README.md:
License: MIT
